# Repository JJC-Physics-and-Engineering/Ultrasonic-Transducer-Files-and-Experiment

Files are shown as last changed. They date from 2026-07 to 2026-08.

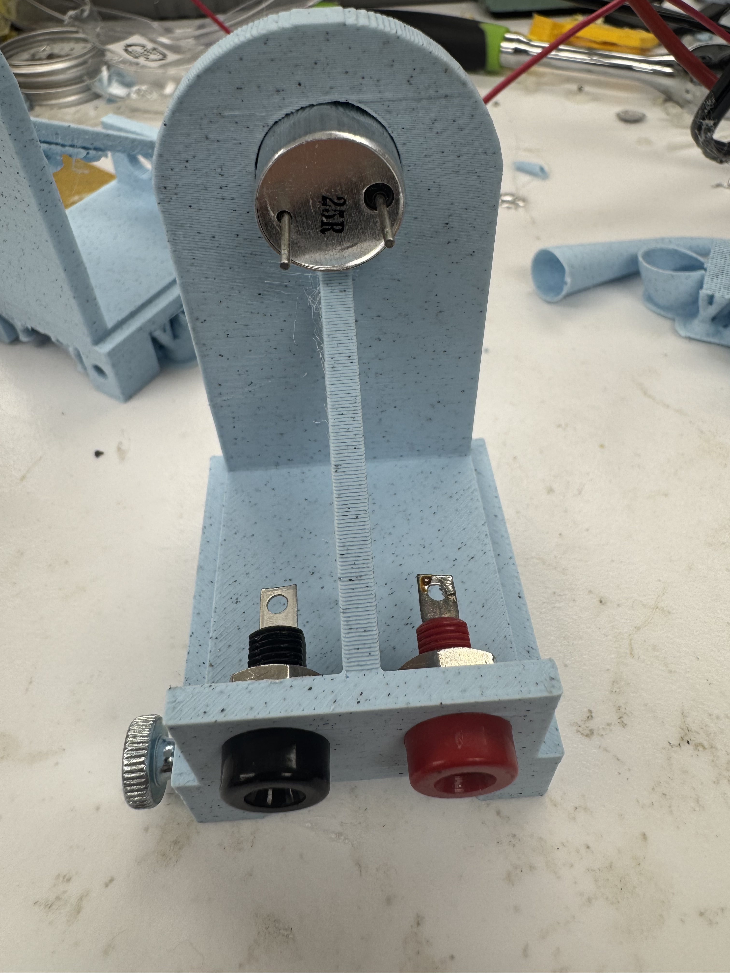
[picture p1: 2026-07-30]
Assembly Instructions/INSTRUCTIONS/Step 5 (Soldering)/1.jpeg

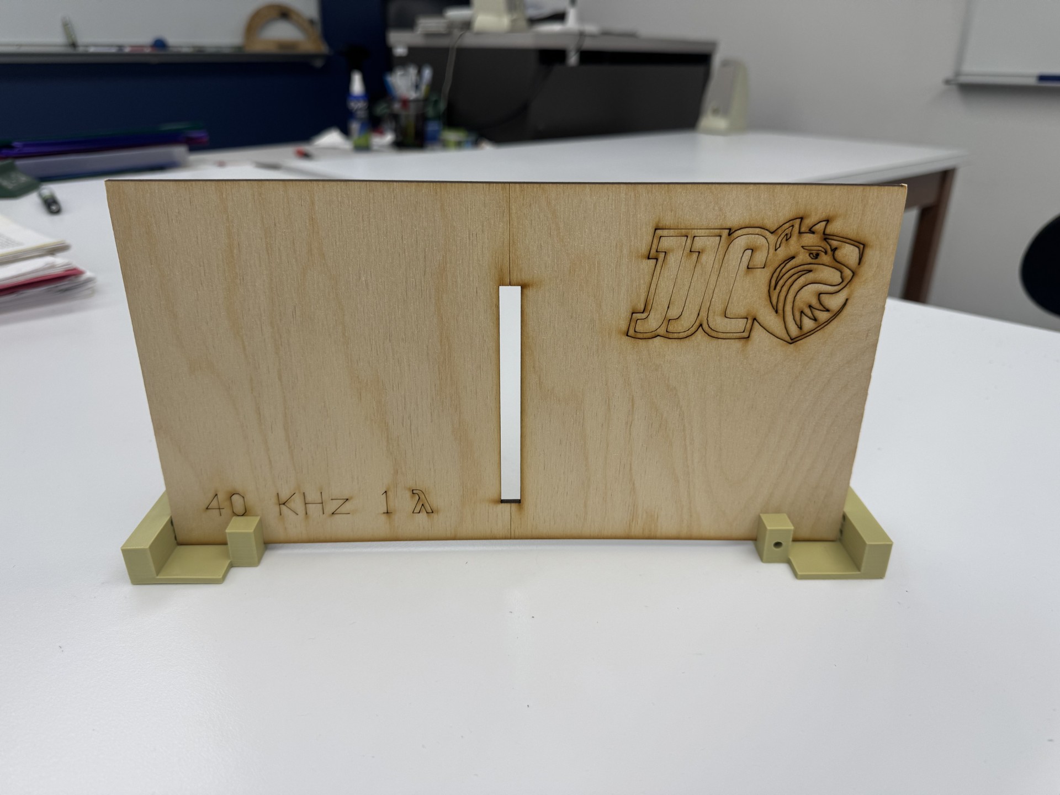
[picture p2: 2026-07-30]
Part Files And Blueprints/Slit experiments/Slit experiment example.jpg

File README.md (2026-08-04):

# Ultrasonic Transducers for the Introductory Physics Laboratory

Open design files, build instructions, and lab activities for a set of low-cost
ultrasonic transmitter/receiver probes used to teach acoustics in introductory
physics laboratory courses.

Each probe is a piezoelectric ultrasonic transducer mounted in a 3D-printed
stand with banana-jack terminals, so it can be driven from an ordinary function
generator and read on an ordinary oscilloscope. The stands clamp to a rail or
meter stick, which makes it straightforward to run quantitative experiments on
the speed of sound, diffraction, and interference with equipment already
present in most teaching labs.

Two frequencies are supported: **25 kHz** and **40 kHz**. Transmitters and
receivers are matched sets — a 25 kHz transmitter must be paired with a 25 kHz
receiver, and likewise for 40 kHz. Color- or shape-coded shrouds make the pairs
easy to tell apart at a glance.

---

## What's in this repository

| Folder | Contents |
| --- | --- |
| [`Part Files And Blueprints/`](Part%20Files%20And%20Blueprints) | CAD source and exports for every printed and cut part: Autodesk Inventor (`.ipt`), STEP (`.stp`), STL, 3MF, and dimensioned PDF blueprints. Also contains the laser-cut slit plates (`.dwg`/`.dxf`). |
| [`3D Print Settings/`](3D%20Print%20Settings) | Recommended slicer settings and plate-orientation screenshots for each printed part. |
| [`Assembly Instructions/`](Assembly%20Instructions) | Parts list with supplier links, required tools and skills, and a photo-illustrated step-by-step build guide. |
| [`Lab activities/`](Lab%20activities) | Student-facing lab handouts — the original experiments plus revised versions written for these transducers, and equipment instructions for the function generator and oscilloscopes. |

---

## Parts to print, cut, and buy

### 3D-printed parts

| Part | Purpose |
| --- | --- |
| Transmitter + Receiver Stand | Holds the transducer and the banana jacks; mounts to a rail or ruler |
| Shrouds (25 kHz T/R, 40 kHz T/R) | Cover the wiring and identify the frequency and role of each probe |
| Ruler square | Reference square for positioning probes along a ruler/rail |
| Slit holder | Holds the laser-cut slit plates upright for diffraction experiments |

All prints were developed on a **Bambu Lab A1** using otherwise standard
profiles. Per-part settings live in `3D Print Settings/<part>/`. In brief:

- Stands, ruler square, and slit holder: 4 wall loops, 30 % cubic infill.
- Shrouds: 2 wall loops, 15 % cubic infill.
- Supports are **on** only for the transmitter/receiver stand; orientation for
  that print matters — see the included example-plate screenshot.
- Several of these prints lift off the plate. A glue stick on the build plate
  is strongly recommended.

Anywhere a part has a **4 mm hole**, it is sized for an M3 heat insert and
thumb screw so the part can be clamped to a rail or ruler.

### Laser-cut parts

Single-slit (λ/4, λ/2, 1λ, 2λ) and double-slit plates are provided for both
25 kHz and 40 kHz, as `.dwg` and `.dxf`. Cut from **20″ × 12″ × 1/8″ plywood**;
choose a plywood with as little resin as possible, since resin-heavy stock cuts
poorly and smokes badly. Laser cutters use proprietary software, so no machine
settings are included — import the DXF into whatever your cutter uses. See
[`Part Files And Blueprints/Slit experiments/READ ME.txt`](Part%20Files%20And%20Blueprints/Slit%20experiments/READ%20ME.txt).

### Purchased parts

Full parts list with supplier links: [`Assembly Instructions/Part List.docx`](Assembly%20Instructions/Part%20List.docx).

**Essential:** ultrasonic transducers (25 kHz and/or 40 kHz transmitter and
receiver pairs), banana jacks with nuts, 18 AWG wire, PLA or PETG filament.
**Optional:** M3 heat inserts, a heat-insert soldering tip, and M3 × 18 mm
thumb screws for rail mounting.

---

## Building a probe

You will need basic soldering skill, basic familiarity with heat inserts, and
patience. Tools: soldering iron and solder, heat-insert tip, wire strippers,
adhesive (super glue, hot glue, or PLA glue), and — highly recommended —
curved needle-nose pliers.

The build is six steps, each with photos in
[`Assembly Instructions/INSTRUCTIONS/`](Assembly%20Instructions/INSTRUCTIONS):

1. **Remove supports** from the printed stand.
2. **Insert heat inserts** into the 4 mm holes.
3. **Insert the transducer.** These are polarized — the positive (black-based)
   prong goes on the right. Press fit or glue.
4. **Insert the banana jacks.** Getting the nuts on without bent needle-nose
   pliers is genuinely painful.
5. **Solder.** Work close to the transducer body and keep the iron moving —
   it is easy to melt the plastic around the jacks or the transducer. Trim the
   transducer prongs short enough that the shroud will seat.
6. **Fit the shroud**, matching it to the transducer's frequency and role.
   Hot glue keeps the probe serviceable; super glue or PLA glue is permanent.

`Assembly Instructions/INSTRUCTIONS/Additional Ideas/` shows how a school logo
can be embedded in the stand (much longer print) or printed separately and
glued on (faster, slightly less clean).

---

## Lab activities

The handouts in [`Lab activities/`](Lab%20activities) are Word documents intended
to be edited for your own course.

**`Original versions from NIU/`** — the source experiments these activities were
built from, along with rewrites tracking the changes made:

- *Experiment 3 — Sinusoidal Motion: The Oscilloscope*
- *Experiment 10 — Speed of Sound* (wavelength via Lissajous figures)
- *Experiment 47 — Acoustic Diffraction and Interference* (single-slit
  diffraction, two-slit interference, Lloyd's mirror, transducer radiation
  pattern)

**`Updated lab activities/`** — revised for these transducers and for modern
benchtop equipment:

- *New speed of sound* — pulse–echo timing. The transmitter is driven in burst
  mode, the reflection off a movable flat surface is timed on the scope, and a
  linear fit of position vs. Δt/2 recovers *c* ≈ 343 m/s.
- *OG Speed of Sound* — the classic wavelength-based version, for comparison.
- *Equipment Instructions* — step-by-step operation of the function generator
  and of both oscilloscope models used in the lab.

Additional activities are planned, including Lloyd's mirror, two-slit
interference, single-slit diffraction, shape detection, airflow between
transducers, and the Doppler effect.

---

## Getting started

1. Print one stand and one shroud per probe, using the settings in
   `3D Print Settings/`. Remember that probes are used in matched pairs.
2. Order the transducers, banana jacks, wire, and (optionally) heat inserts and
   thumb screws from the parts list.
3. Build each probe following `Assembly Instructions/`.
4. Laser-cut the slit plates and print the slit holder and ruler square if you
   plan to run the diffraction and interference activities.
5. Adapt the handouts in `Lab activities/` to your course, checking the
   resonant frequency of the transducers you actually bought.

---

## Repository notes

- CAD is provided as native Inventor `.ipt` alongside neutral STEP and STL, so
  parts can be modified in most CAD packages.
- `.bak`, `.dwl`, and `.dwl2` files in the slit folders are AutoCAD backup and
  lock artifacts; the `.dwg` and `.dxf` files are the ones you want.
- Some folder and file names use the spelling "Reciever". These are preserved
  as-is so paths continue to match the CAD assemblies and instructions.

## Authors and acknowledgments

<!-- TODO: add student and faculty contributors, institution, and any grant or
     program support. -->

The original lab experiments derive from the physics laboratory manual used at
Northern Illinois University and reference T. D. Rossing, *The Science of Sound*.

## License

<!-- TODO: choose a license. For a project like this, a split license is common:
     e.g. CERN-OHL-S or CC BY-SA 4.0 for the hardware and design files, and
     CC BY-NC-SA 4.0 or CC BY 4.0 for the lab handouts. -->

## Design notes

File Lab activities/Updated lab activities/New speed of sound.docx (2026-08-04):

Experiment 10

SPEED OF SOUND

APPARATUS: Ultrasonic crystals, audio generator, oscilloscope

DISCUSSION: The speed of sound in an ideal gas is given by:

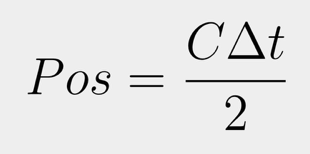
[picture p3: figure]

Pos is position C is speed of sound t is time

Your ultrasonic transducers may have a different resonant frequency. You may need to check with your instructor.

The sound waves are reflecting off the surface and back causing the change in time to be double, in order to account for this delta t is divided by 2.

PROCEDURE:

1. Drive the transmitting crystal with an audio generator and connect the receiving crystal to the vertical input of an oscilloscope. With the receiver and transmitter next to each other and a solid flat surface 5 cm in front of them, tune the generator to the resonant frequency of the crystals.

2. Set the function generator to resonant frequency with 5V peak to peak (Vpp) and use burst at 6 cycles with one second burst period. Set the oscilloscope by using both cursors (one for beginning of the transmitter wave and one for the beginning of the receiver wave) and use time scale 1 millisecond division.

3. Take many recordings of the position of the solid flat surface vs the time delay (the delta t). Record in the table attached.

4. In Logger Pro, input time delay in the x column. Then input the position in the y column. The final product will have (delta t/2) in seconds (if your time is in milliseconds, divide by 1000) on the x-axis and position in meters (if your position is in cm, divide by 100 to get to meters) on the y-axis. When this is achieved, click analyze > linear fit. The slope should be around 343 m/s.

DATA SHEET AND MINI-REPORT: Experiment 10

Position (cm) | Delta t (ms)
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
C = ___________ m/s

*The specific numbers chosen for the position do not matter. The above numbers are suggestions not recommendations.

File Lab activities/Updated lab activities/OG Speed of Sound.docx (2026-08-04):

Experiment 10

SPEED OF SOUND

APPARATUS: Ultrasonic crystals, audio generator, oscilloscope

REFERENCE: Rossing, The Science of Sound, Section 3.5

DISCUSSION: The speed of sound in an ideal gas is given by:

T is absolute temperature M is molecular weight R is the gas constant.

Note that the speed varies directly with temperature but is independent of pressure. (In a real gas, there is a slight dependence on pressure, but it is quite small).

In this experiment, the speed of sound is determined by measuring frequency and wavelength and using the relationship: v = fγ. The sound source and receiver are both ceramic crystals of the type formerly used in television remote control units. (Remote controls of this type used to make an audible “click”. For this reason, they were referred to as “clickers”.) They resonate at about 40 kHz, well above the limit of hearing (dogs or bats might not enjoy this experiment!). Your ultrasonic transducers may have a different resonant frequency. You may need to check with your instructor.

PROCEDURE:

1. Drive the transmitting crystal with an audio generator, and connect the receiving crystal to the vertical input of an oscilloscope. With receiver and transmitter 5 – 10 cm apart, tune the generator to the resonant frequency of the crystals.

2. To measure the wavelength, vary the distance between the crystals, and locate positions that are some integral number of wavelengths apart. This can be done by connecting the receiving crystal to the vertical input of the oscilloscope, and the generator output to the horizontal input, to display a fy vs fx Lissajous pattern whose shape varies with the phase of the signal from the receiver.

Since the precision of the result depends strongly on the measurement of the wavelength, it is wise to average several measurements to determine the best value of λ. One way to do this would be to make 6 or more determinations of 10λ using different initial spacings of receiver and transmitter (why measure 10λ rather than λ?)

3. Measure the frequency of the audio generator with a frequency counter. Calculate the speed of sound from the formula: v = fγ. Compare it to the value given in Table 3.1 of Rossing (corrected to the temperature in your room.)

If time permits:

4. Measure the attenuation of 40 kHz ultrasound by various materials (paper, Styrofoam, etc.) by noting the difference in amplitude of the signal with and without the absorber in its path.

DATA SHEET AND MINI-REPORT: Experiment 10

10λ (cm) | Frequency (Hz)

To find the wavelength: Take all the lengths found for 10λ, add them together, and divide them by 6 (or however many determinations found). This number is your average for 10λ. Take the average for 10λ and divide it by 10 to find λ.

λ = _______m

t = ______ °C

V(t) = ______

v = fγ

T = ________K

Discussion: Estimate the uncertainty in λ and f. Call these Δλ and Δf.

Calculate the uncertainty in speed Δv from the formula:

Does v Δv span the calculated value v(T)?

27 SPEED OF SOUND

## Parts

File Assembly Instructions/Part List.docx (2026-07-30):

Parts List

ESSENTIAL

- Banana Jacks: https://www.mouser.com/en/ProductDetail/530-108-0903-1  https://www.mouser.com/en/ProductDetail/Johnson-Cinch-Connectivity-Solutions/108-0902-001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
- Transducers: https://a.co/d/07uBKIS6  https://a.co/d/09vyZoEI  https://a.co/d/0f3AuWEN
- 18 Gauge Wire
- PETG/PLA Filament

Optional

- M3 Heat Inserts: https://a.co/d/02u2SNHs
- Heat Insert Tips: https://a.co/d/04KGmkFV
- M3 X 18mm Thumb Screws: https://a.co/d/0bNqlTka

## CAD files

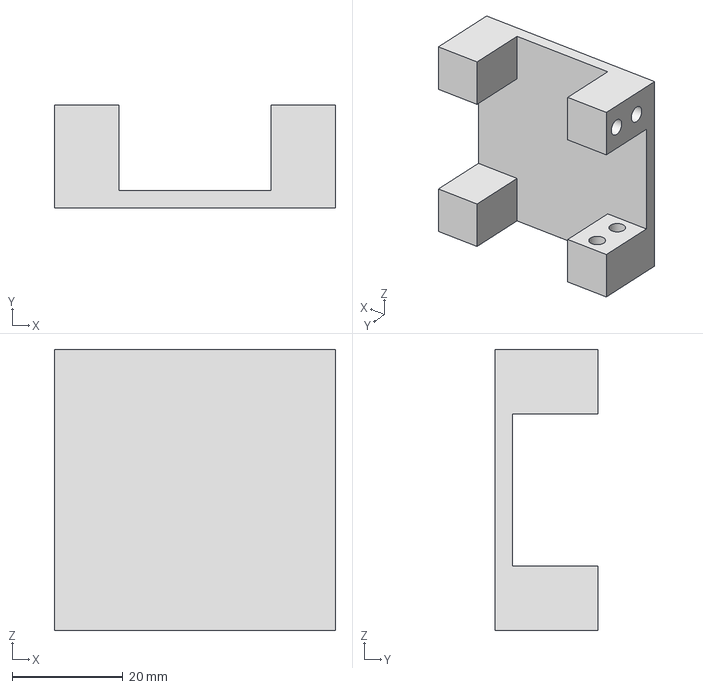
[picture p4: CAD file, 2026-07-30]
Part Files And Blueprints/Ruler square/Ruler square.stp
50.8 x 18.7 x 50.8 mm

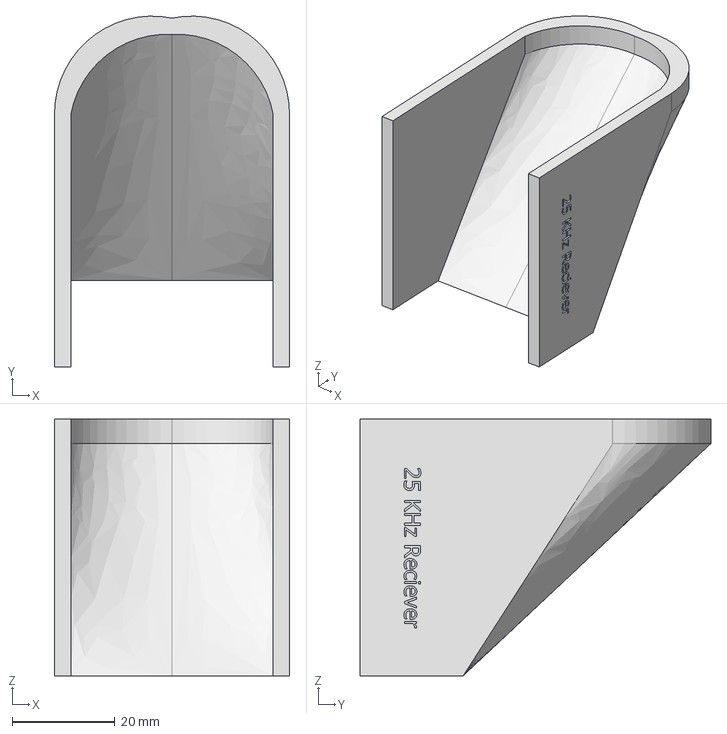
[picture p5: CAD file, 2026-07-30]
Part Files And Blueprints/Shrouds/25Khz Reciever/Shroud 25 R.stp
45.7 x 68.2 x 50.0 mm

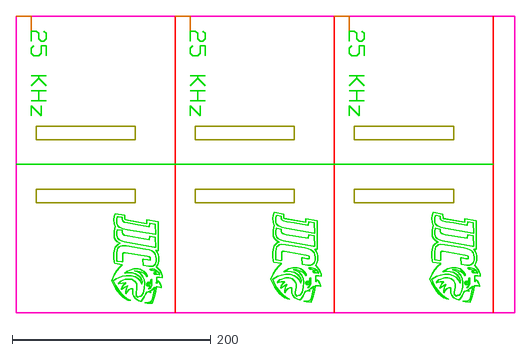
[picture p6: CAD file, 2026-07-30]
Part Files And Blueprints/Slit experiments/Double Slit 25Khz/25 Khz double slit.dxf
501.6 x 298.5

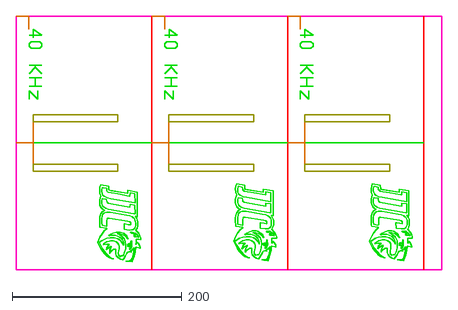
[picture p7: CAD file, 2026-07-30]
Part Files And Blueprints/Slit experiments/Double Slit 40Khz/40 Khz double slit.dxf
501.7 x 298.5

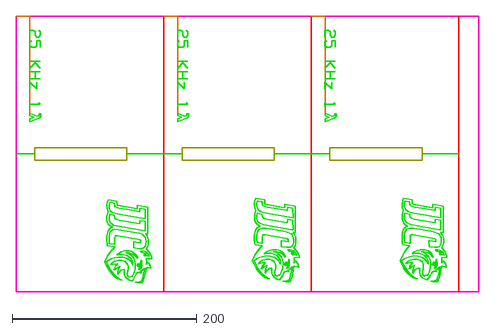
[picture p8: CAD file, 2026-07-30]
Part Files And Blueprints/Slit experiments/Single Slit 25Khz/1/25 Khz single 1.dxf
501.6 x 298.5

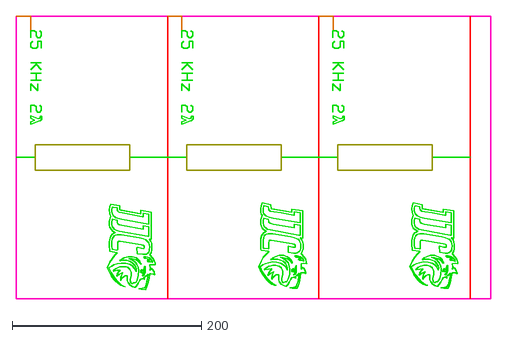
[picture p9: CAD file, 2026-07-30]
Part Files And Blueprints/Slit experiments/Single Slit 25Khz/2/25 Khz single 2.dxf
501.6 x 298.5

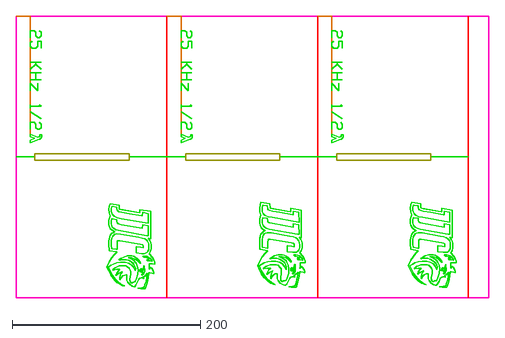
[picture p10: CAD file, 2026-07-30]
Part Files And Blueprints/Slit experiments/Single Slit 25Khz/half/25 Khz single half.dxf
501.6 x 298.5

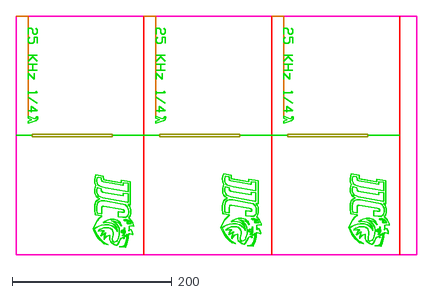
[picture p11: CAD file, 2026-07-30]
Part Files And Blueprints/Slit experiments/Single Slit 25Khz/quarter/25 Khz single quarter.dxf
501.6 x 298.5

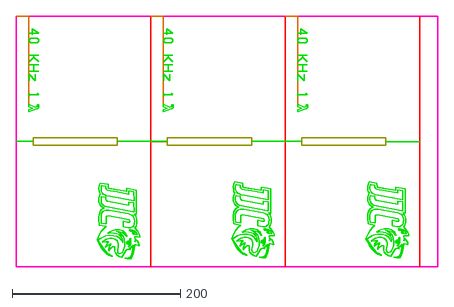
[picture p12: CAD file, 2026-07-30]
Part Files And Blueprints/Slit experiments/Single Slit 40Khz/1/40 Khz single 1.dxf
501.6 x 298.4

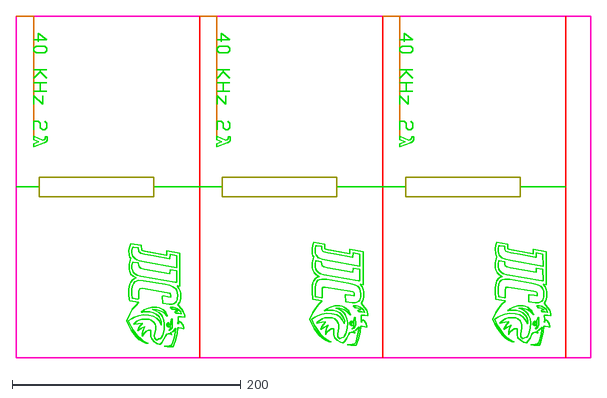
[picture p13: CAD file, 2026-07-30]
Part Files And Blueprints/Slit experiments/Single Slit 40Khz/2/40 Khz single 2.dxf
501.6 x 298.5

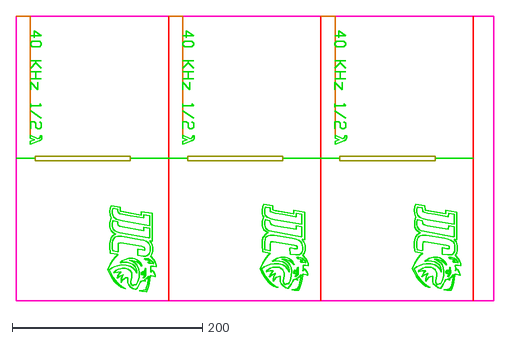
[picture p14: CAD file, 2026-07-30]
Part Files And Blueprints/Slit experiments/Single Slit 40Khz/half/40 Khz single half.dxf
501.6 x 298.5

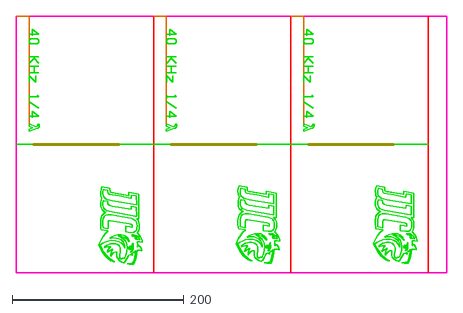
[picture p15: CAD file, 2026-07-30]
Part Files And Blueprints/Slit experiments/Single Slit 40Khz/quarter/40 Khz single quarter.dxf
501.6 x 298.5

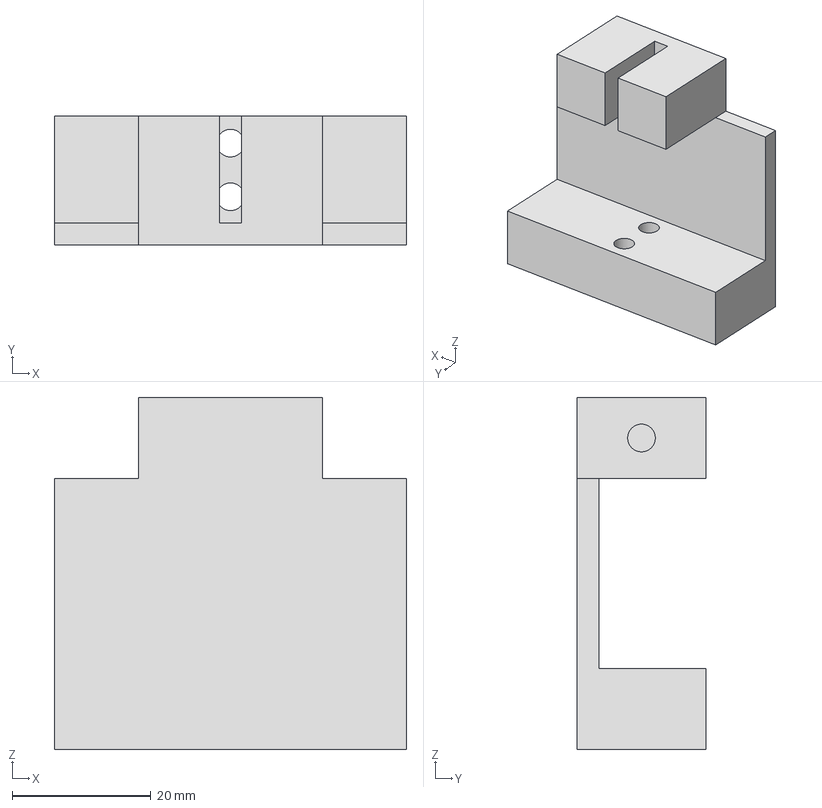
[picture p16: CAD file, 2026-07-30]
Part Files And Blueprints/Slit experiments/Slit experiment holder/Slit holder.stp
50.8 x 18.7 x 50.8 mm

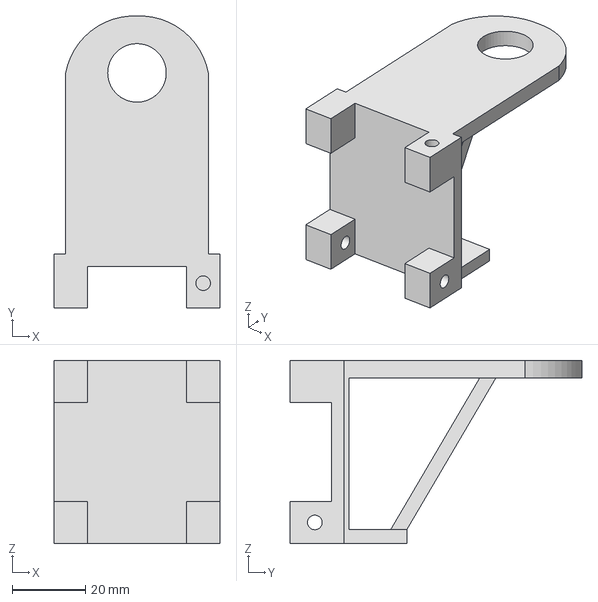
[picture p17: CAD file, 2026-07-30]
Part Files And Blueprints/Transmitter + Reciever Stand/Transmitter + Reciever.stp
45.3 x 79.8 x 50.0 mm

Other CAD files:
Part Files And Blueprints/Shrouds/25Khz Transmitter/Shroud 25 T.stp
Part Files And Blueprints/Shrouds/40Khz Reciever/Shroud 40 R.stp
Part Files And Blueprints/Shrouds/40Khz Transmitter/Shroud 40 T.stp
Part Files And Blueprints/Ruler square/Ruler square.ipt
Part Files And Blueprints/Ruler square/Ruler square.stl
Part Files And Blueprints/Shrouds/25Khz Reciever/Shroud 25 R.3mf
Part Files And Blueprints/Shrouds/25Khz Reciever/Shroud 25 R.ipt
Part Files And Blueprints/Shrouds/25Khz Reciever/Shroud 25 R.stl
Part Files And Blueprints/Shrouds/25Khz Transmitter/Shroud 25 T.ipt
Part Files And Blueprints/Shrouds/25Khz Transmitter/Shroud 25 T.stl
Part Files And Blueprints/Shrouds/40Khz Reciever/Shroud 40 R.ipt
Part Files And Blueprints/Shrouds/40Khz Reciever/Shroud 40 R.stl
Part Files And Blueprints/Shrouds/40Khz Transmitter/Shroud 40 T.ipt
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

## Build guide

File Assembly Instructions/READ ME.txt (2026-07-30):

In Order to Assemble a Transmitter or Receiver You Need to Have the Following Tools, Parts, and Skills

--------------------------------------------------

SKILLS

--------------------------------------------------

Basic proficiency with a soldering iron

Basic use of heat inserts

Patience

--------------------------------------------------

TOOLS

--------------------------------------------------

Soldering Iron

Solder

Heat insert insertion tip

Curved needle nose pliers (Optional)

Some type of adhesive (either Super glue, Hot glue, or PLA glue)

Wire stripers

--------------------------------------------------

Parts

--------------------------------------------------

Transmitter or Receiver Stand

Transmitter or Receiver

Banana Jacks with nuts

18 gauge wire

Shroud

Heat Inserts

--------------------------------------------------

Notes

--------------------------------------------------

I will include a visual step by step guide in the form of txt and png files labeled in numerical order

Just a reminder that these probes are a set so you MUST have a 25Khz receiver paired with a 25Khz transmitter and the same applies to the 40Khz receivers and transmitters.

--------------------------------------------------

IMPORTANT

--------------------------------------------------

WHEREVER YOU SEE A 4mm HOLE ON ANY PART, IT IS DESIGNED FOR A HEAT INSERT AND THUMB SCREW TO ALLOW YOU TO SECURE THE PART TO A RAIL/RULER.

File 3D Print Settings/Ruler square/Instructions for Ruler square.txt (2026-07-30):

3D Print Settings

All prints use standard print settings for Bambu A1 unless stated

----------

Wall Loops: 4

Sparse Density Infill: 30%

Sparse Infill Pattern: Cubic

Enable Support: OFF
----------

Notes

This Print Likes to lift off of the plate. Use a glue stick on the plate to avoid this.

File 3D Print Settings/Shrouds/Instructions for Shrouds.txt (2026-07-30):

3D Print Settings

All prints use standard print settings for Bambu A1 unless stated

----------

Wall Loops: 2

Sparse Density Infill: 15%

Sparse Infill Pattern: Cubic

Enable Support: OFF

----------

Notes

Print is prone to fail early on. watch the 3D printer closely until the first few layers are complete. Glue Stick on the plate helps tons.

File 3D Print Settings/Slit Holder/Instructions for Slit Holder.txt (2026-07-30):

3D Print Settings

All prints use standard print settings for Bambu A1 unless stated

----------

Wall Loops: 4

Sparse Density Infill: 30%

Sparse Infill Pattern: Cubic

Enable Support: OFF

----------

Notes

Once again this print likes to lift off of the plate so using a glue stick on the plate helps a lot.

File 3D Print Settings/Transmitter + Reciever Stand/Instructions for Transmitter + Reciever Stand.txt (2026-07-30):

3D Print Settings

All prints use standard print settings for Bambu A1 unless stated

----------

Wall Loops: 4

Sparse Density Infill: 30%

Sparse Infill Pattern: Cubic

Enable Support: ON

----------

Notes

Orientation is very important for this print. Please see included screenshot for proper orientation.

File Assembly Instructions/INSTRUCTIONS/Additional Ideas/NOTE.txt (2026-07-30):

It is possible to embed your schools logo into the stand which makes them much more visually appealing however this effects the length of the print GREATLY.

I choose to print my schools logo separately and glue them on which is not as clean looking but is much faster and less complex.

I will provide examples of both so you can decide if it is worth the effort.

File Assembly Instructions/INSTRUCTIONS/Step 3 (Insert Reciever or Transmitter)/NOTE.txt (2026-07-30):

I usually press fit these in but feel free to glue them in if you wish.

Also these are polarized so mate sure you have the positive (black based prong) on the right side.

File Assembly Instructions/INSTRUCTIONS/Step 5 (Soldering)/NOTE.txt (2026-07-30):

Take your time here, since it is very easy to overheat the banana jacks or transmitter/receiver while soldering which can melt the plastic around both of them.

Also you will need to trim the prongs of the receiver/transmitter down so the shroud can fit on the stand so try to solder close to the body of the receiver/transmitter.

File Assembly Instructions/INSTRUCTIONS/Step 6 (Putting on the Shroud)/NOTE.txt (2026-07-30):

Make sure that your specific transmitter/receiver has its corresponding shroud so it is easy to tell which probes are which at a glance.

I used hot glue to secure the shroud to the stand so It could be serviced in the future. If serviceability isn't a concern to you feel free to superglue or PLA glue the two parts together

If using hot glue I HIGHLY recommend the Stanley hot glue sticks since they seem to work the best in my opinion

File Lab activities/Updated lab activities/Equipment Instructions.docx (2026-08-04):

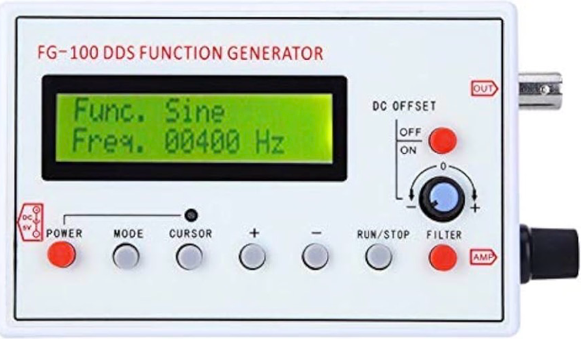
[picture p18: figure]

How to use the function generator and oscilloscopes:

Function generator:

- To allow it to power on, use a DC plug on the left side and have it connected to a power outlet. Click the power button.
- On the right side, using the top silver output insert a splitter with banana jacks.
- One set of the red and black cords will connect to the oscilloscope, and the other set will connect to the transmitter.
- The mode button will change how the waves appear on the screen of the oscilloscope. The main mode used is sine.
- The cursor button allows you to move digits to the right and the plus or minus will change the number where the cursor is over.
  - If using a 40KHz receiver and transmitter, the number should read 40000 Hz.
- The DC offset button will move the yellow line on the oscilloscope up or down.
- The AMP dial will make the sound waves on your screen appear bigger or smaller.
- When all the settings are correct, click the run/stop button. If any setting ever needs to be changed, click the run/stop button to edit the settings.

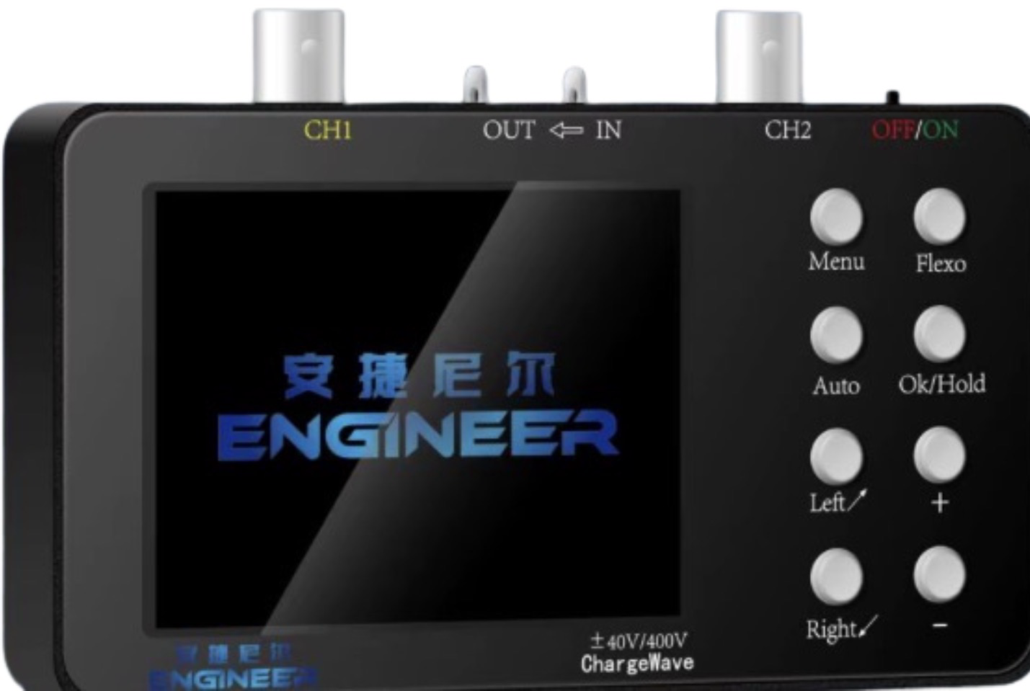
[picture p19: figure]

Oscilloscope 1:

- To power on, plug in USB-C cord into the right side of the oscilloscope and flip it to on with the switch on the top right. If fully charged, it will not need to be plugged in.
- Put splitters on each of the silver channels on the top. Insert the second set of black and red cords from the function generator into the splitter of CH1.
- In the splitter of CH2, insert the black and red cords from the receiver.
- The left and right buttons are used to move the cursor to allow for things on the screen to be selected and changed. Things can be changed by using the + and – buttons.
- The Ok/Hold button pauses the screen.
- In the top right corner of the screen there is a box that can say auto, single, or normal. Single freezes the screen and auto is the most used.
- The top and bottom left boxes are not needed to be changed. Auto can be used instead.
- The bottom middle box when increased, zooms out and vice versa.

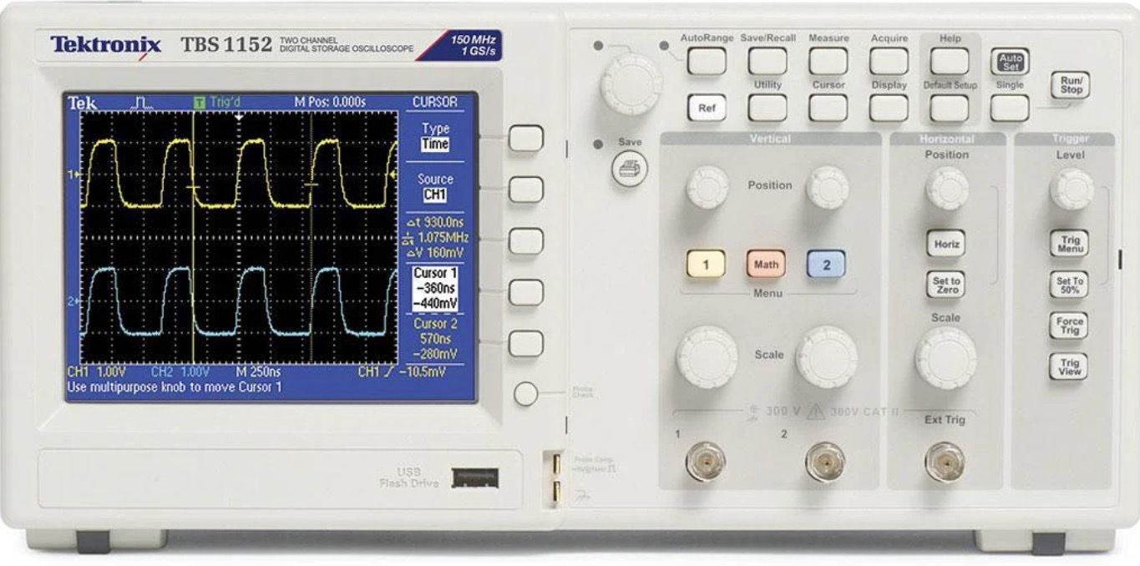
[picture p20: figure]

Oscilloscope 2

- Plug power cord in back and connect to power source.
- Put splitters on each of the silver channels on the bottom of the front. Insert the second set of black and red cords from the function generator into the splitter of 1.
- In the splitter of 2, insert the black and red cords from the receiver.
- Power button is top left of machine, press it down to turn it on.
- In the vertical dark grey rectangle, there are four dials.
  - The top left dial moves the yellow wave from the transmitter up or down.
  - The top right dial moves the blue wave from the receiver up or down.
  - The bottom left dial makes the yellow wave bigger or smaller.
  - The bottom right dial makes the blue wave bigger or smaller.
- The Horizontal box only has two dials.
  - The top one moves both waves to the left and right.
  - The bottom one makes it take longer or shorter to move across the screen.
- The trigger box only has one dial.
  - It freezes the trace.
- The top dial, not in any box, changes the setting from auto to triggered.

SET UP PICTURED:

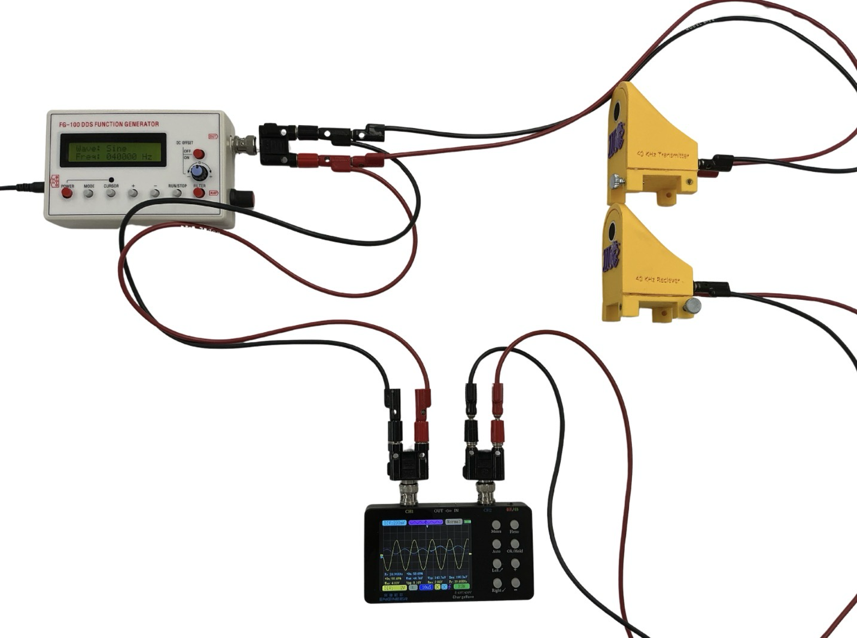
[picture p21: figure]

Instruction manual for how to use the equipment needed for the experiments

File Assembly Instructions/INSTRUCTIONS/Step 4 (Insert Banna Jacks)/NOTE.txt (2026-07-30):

If you don't have bent needle nose pliers getting the nuts on the banana jacks is a real pain.

If you don't care about future serviceability gluing in the banana jacks could also work and would save time.

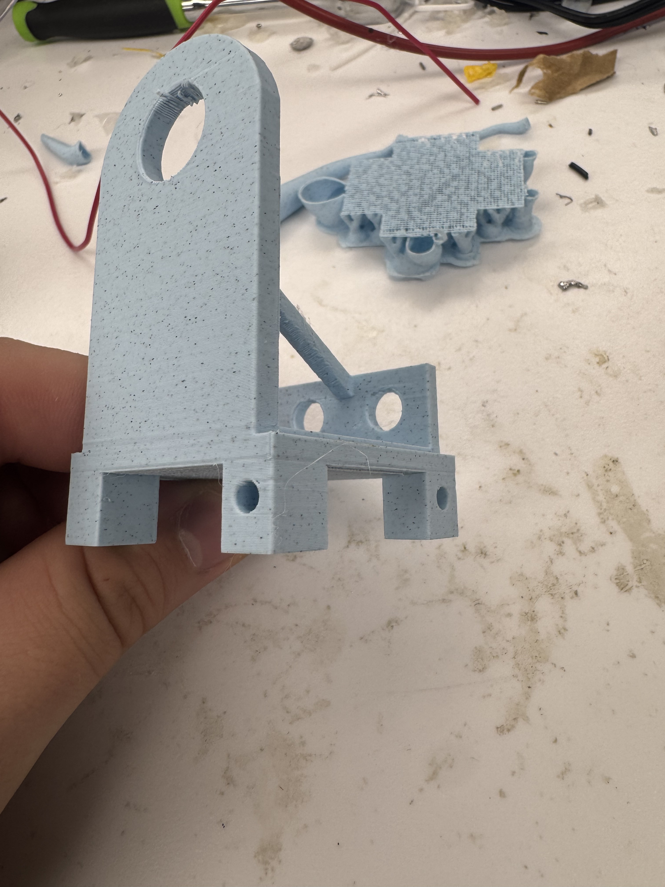
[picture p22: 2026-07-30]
Assembly Instructions/INSTRUCTIONS/Step 2 (Insert Heat Insets)/1.jpeg

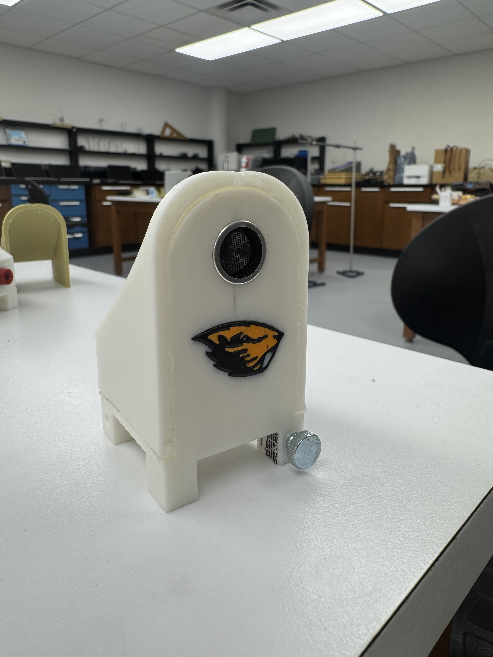
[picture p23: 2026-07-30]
Assembly Instructions/INSTRUCTIONS/Additional Ideas/2.jpeg

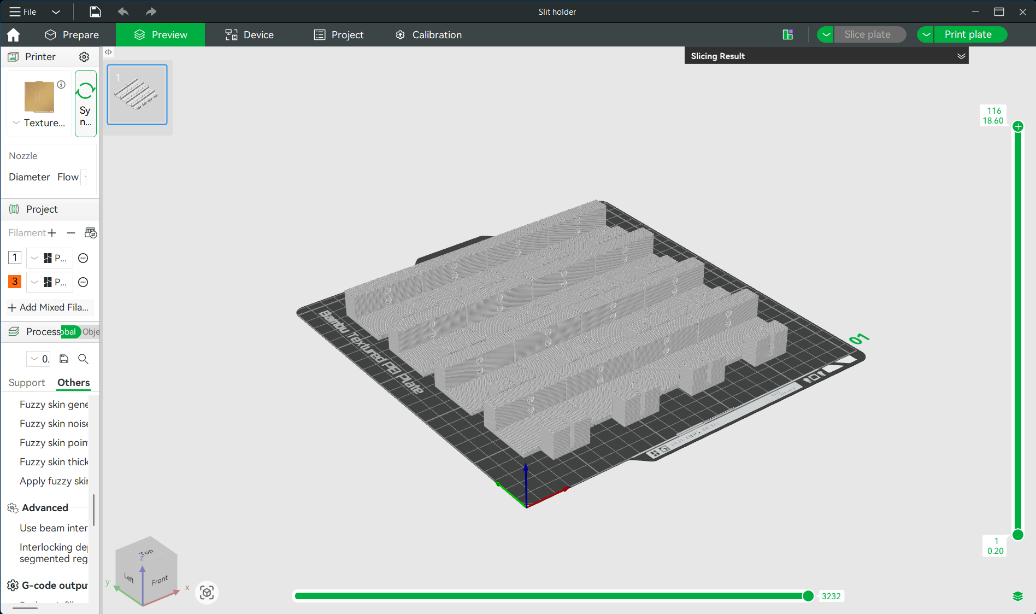
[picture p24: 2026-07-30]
3D Print Settings/Slit Holder/Example plate.png

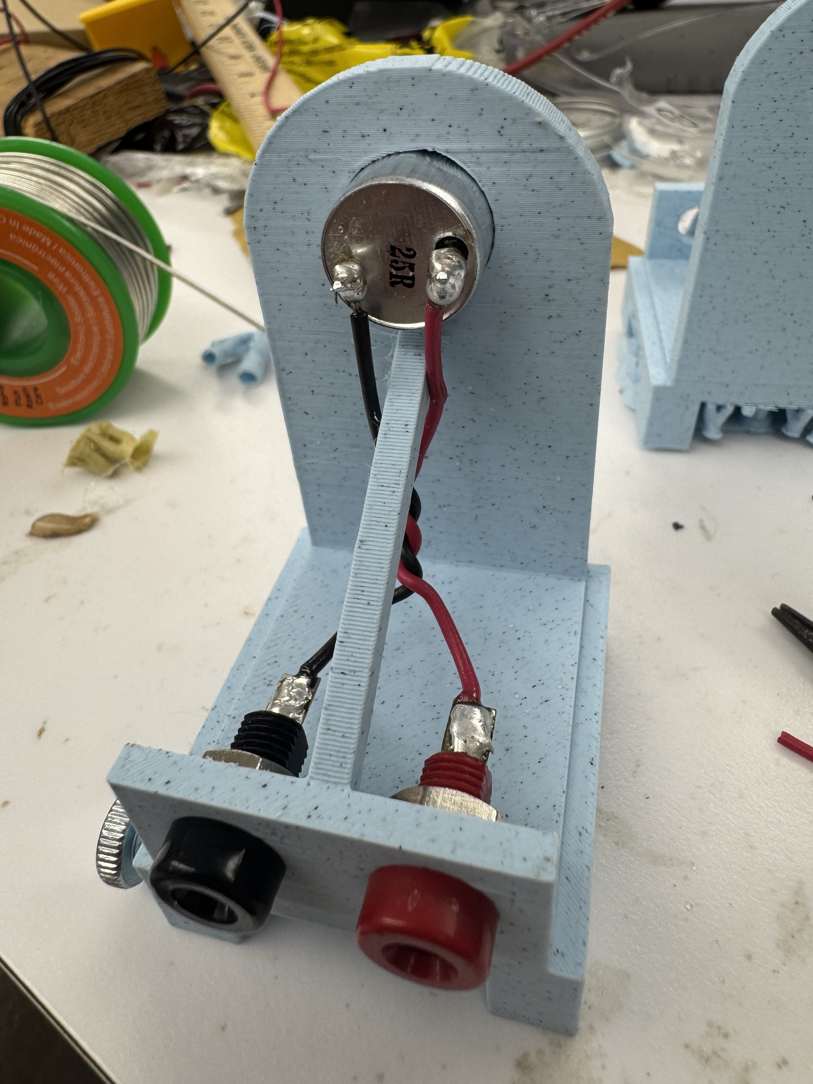
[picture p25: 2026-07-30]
Assembly Instructions/INSTRUCTIONS/Step 5 (Soldering)/3.jpeg

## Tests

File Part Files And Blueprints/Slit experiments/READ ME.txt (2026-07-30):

In Regards to the slit experiments:

I decided to include the files for the slit experiments since I A) already made them, and B) They are a good introduction to how our probes work. However, I am unable to provide clear instructions on the setup and settings of the laser cutter that made them since unlike 3D printers, laser cutters tend to use their own proprietary software that makes any instructions here pointless for most users. So I am unable to provide clear instructions but I am able to provide the files used, what materials we used, and photo of the finished product. The included DXF files should be able to be imported to most laser cutting software pretty easily.

MATERIAL:

20'' X 12'' X 1/8'' Plywood

NOTES:

Try to get a plywood with as little resin as possible since high amounts of resin are harder to cut and produce MUCH more smoke.

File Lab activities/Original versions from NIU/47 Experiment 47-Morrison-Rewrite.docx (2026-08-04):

Experiment 47

ACOUSTIC DIFFRACTION AND INTERFERENCE

APPARATUS: Ultrasonic crystals, audio generator, oscilloscope, and audio voltmeter.

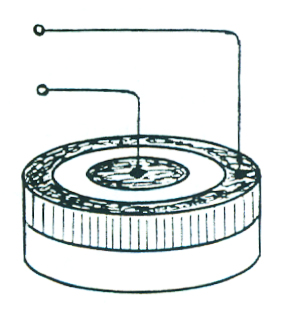
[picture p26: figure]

REFERENCES: T.D. Rossing, The Science of Sound, Sections 3.10, 3.11; A.M. Portis and H.D. Young, Berkeley Physics Laboratory, 2nd ed. (McGraw-Hill, New York, 1971). AF-2; F.W. Sears, M.W. Zemansky, and H.D. Young, College Physics, 5th ed. (Addison-Wesley, Reading, MA, 1980). Chapter 42.

DISCUSSION:

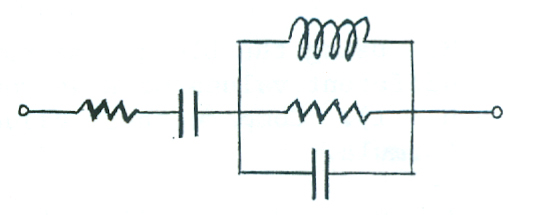
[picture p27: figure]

This experiment makes use of the same ultrasonic transducers used to determine the speed of sound in Experiment 10. These transducers, which were developed for the remote control of television receivers, consist of discs of piezoelelctric barium titanate bonded to aluminum. Two electrodes are attached to each barium titanate disc and applying a voltage to these electrodes causes the BaTiO3 to warp, thus exciting a strong mechanical resonance at 40 kHz in the aluminum disc (other resonances can also be observed at high frequencies.) An equivalent electrical circuit for the transducer is shown.

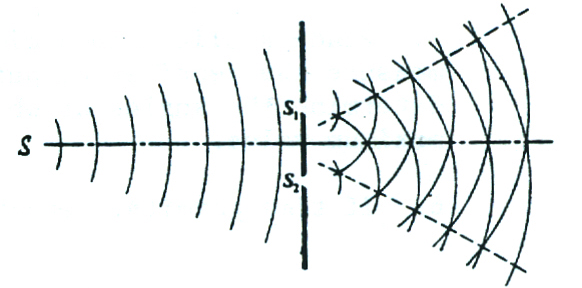
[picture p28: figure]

Many classical optics experiments can be conveniently performed using these transducers to generate and detect ultrasonic single-slit diffraction, two-slit interference, and Lloyd’s mirror. In addition, the radiation pattern of a single transducer will be explored.

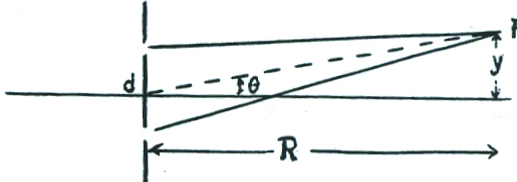
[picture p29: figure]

One of the earliest demonstrations of wave interference was performed by Thomas Young around 1800. Waves from source S pass through slits S1 and S2 and interfere in the region beyond them. Constructive interference will occur at point P located so that y = R nλ/d where d is the distance between the slits, λ is the wavelength, and n is an integer

Lloyd’s mirror may be thought of as a variation of Young’s experiment in which the image S1 of source S acts as the second source. Because there is a reversal of phase upon reflection at the table top, however, S and S1 act as sources with opposite phase (compare Fig. 25.2 in Rossing)

Therefore, constructive interference should occur when ;

but y = d/2, so we can write

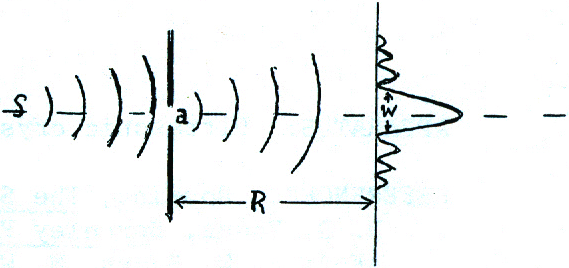
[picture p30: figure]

as the condition for a maximum.

The diffraction pattern of a single slit consists of a central maximum along with secondary maxima on either side. The width w of the central maximum is given approximately by , where a is the width of the slit.

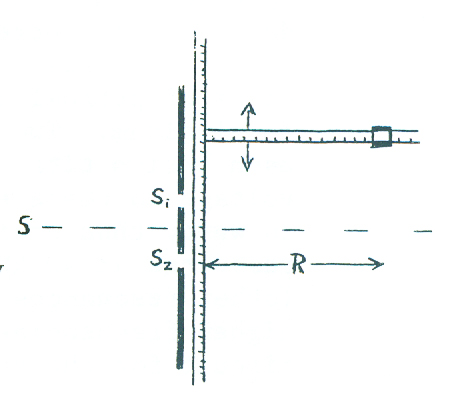
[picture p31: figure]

PROCEDURE:

1. Set up the transmitting and receiving crystals as described in Experiment 10. Either measure the wavelength (as in Step 2) or calculate it from the measured frequency.

2. Place one crystal about 50 cm away from a pair of slits having a spacing of about 5 cm. With R = 50 cm, measure y for 5-7 maxima (2 or 3 on each side of the central one). Compare these values of y to those predicted by the formula again.

3. Using the Lloyd’s mirror arrangement, measure as many different values or R as you can (including the one for n = 1). Compare these values to those predicted by the formula.

4. Connect an audio voltmeter (VTVM) across the receiver crystal in order to more accurately measure small voltages. Carefully measure the output of the receiving transducer placed at intervals of 15° on a semicircle with the transmitter at the center. Determine the average angles at which the signal drops to one half of its value on the axis. At what angle does it drop to one tenth of its maximum value?

5. Place a slit with a width of about 2λ about 20 cm away from the transmitter and measure the receiver output on a semicircle with the slit at the center. Again determine the angles at which the signal drops to one half and one tenth of its maximum value.

6. If time permits, repeat Step 5 with a slit having a width of about ½.

143 ACOUSTIC DIFFRACTION AND INTERFERENCE

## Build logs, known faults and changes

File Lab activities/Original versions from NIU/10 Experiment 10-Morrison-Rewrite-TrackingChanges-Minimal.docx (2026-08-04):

Experiment 10

SPEED OF SOUND

APPARATUS: Ultrasonic crystals, audio generator, oscilloscope

REFFERENCE: Rossing, The Science of Sound, Section 3.5

DISCUSSION:

The goal of this experiment is to experimentally determine the speed of sound in air using ultrasonic transducers. One transducer will function as a sound wave transmitter; the other transducer will function as a sound wave receiver.

PROCEDURE:

1. Drive the transmitting crystal with an audio generator and connect the receiving crystal to the vertical input of an oscilloscope. Spend a few minutes familiarizing yourself with the qualitative behavior of the transducers.

Determine the resonant frequency of the crystals.

2. Devise a method of measuring the wavelength of the sound wave emitted by the transmitting transducer. It may be useful to connect the receiving crystal to the vertical input of the oscilloscope, and the generator output to the horizontal input, to display a fy vs fx Lissajous pattern whose shape varies with the phase of the signal from the receiver.

Be sure to be able to discuss the precision with which you can determine the wavelength.

3. Record the frequency of the signal from the audio generator with a frequency counter. Calculate the speed of sound. Compare it to the value given in Table 3.1 of Rossing (corrected to the temperature in your room.)

If time permits:

4. Measure the attenuation of 40 kHz ultrasound by various materials (paper, Styrofoam, etc.) by noting the difference in amplitude of the signal with and without the absorber in its path.

DATA SHEET AND MINI-REPORT : Experiment 10

(To be used if a laboratory notebook is not kept)

λ = m v = fγ

t = °C T = K

v(T) =

2, 3)

| 10λ | f
| cm | Hz
Average

Discussion: Estimate the uncertainty in λ and f. Call these Δλ and Δf.

Calculate the uncertainty in speed Δv from the formula:

Does v Δv span the calculated value v(T)?

4)

27 SPEED OF SOUND

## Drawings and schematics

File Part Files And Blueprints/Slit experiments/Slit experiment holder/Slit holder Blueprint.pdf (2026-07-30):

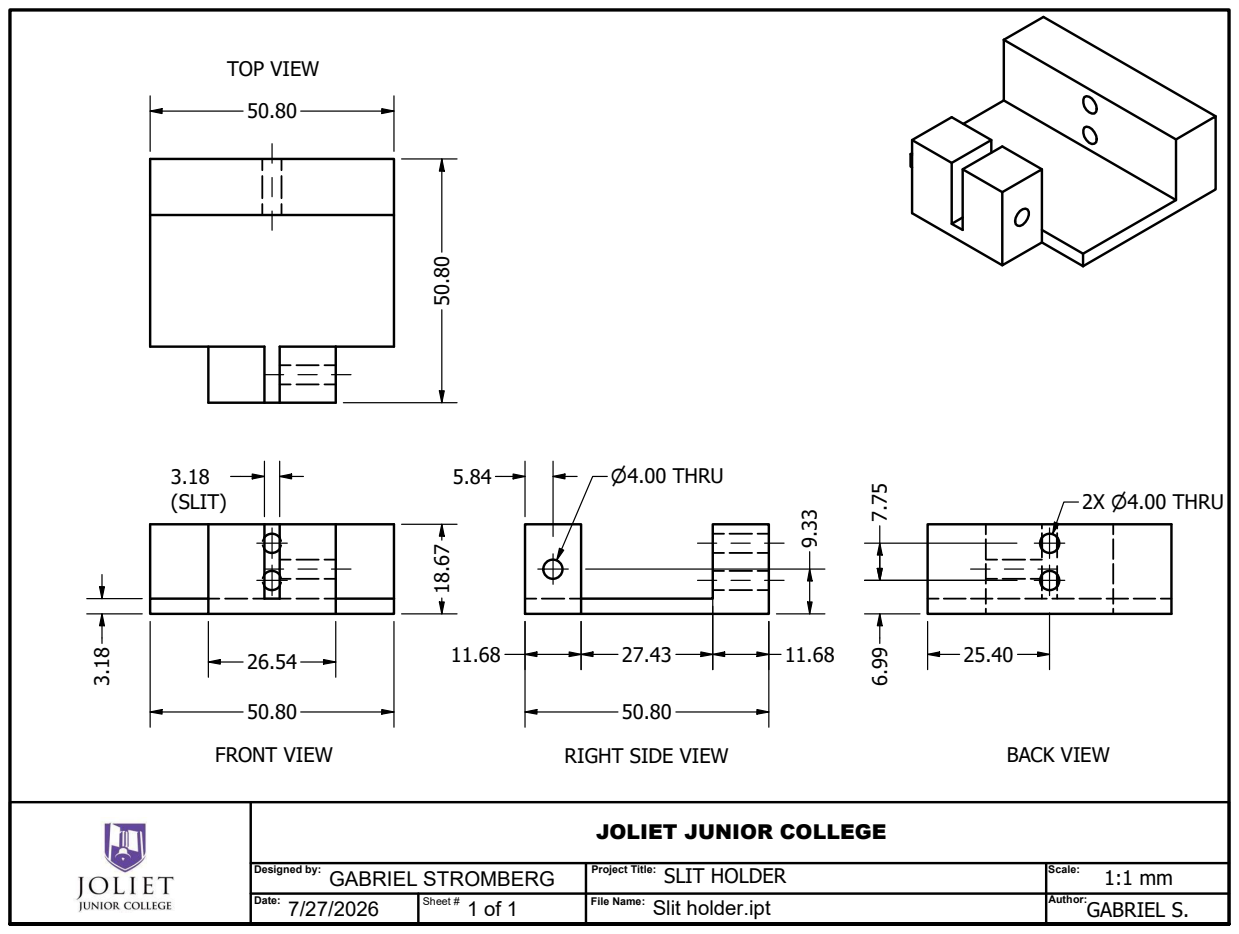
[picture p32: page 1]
⌀4.00 THRU; 2X ⌀4.00 THRU; TOP VIEW; FRONT VIEW; RIGHT SIDE VIEW; BACK VIEW

JOLIET JUNIOR COLLEGE

Designed by: GABRIEL STROMBERG | Project Title: SLIT HOLDER | Scale: 1:1 mm

Date: 7/27/2026 | Sheet # | File Name: Slit holder.ipt | Author: GABRIEL S.

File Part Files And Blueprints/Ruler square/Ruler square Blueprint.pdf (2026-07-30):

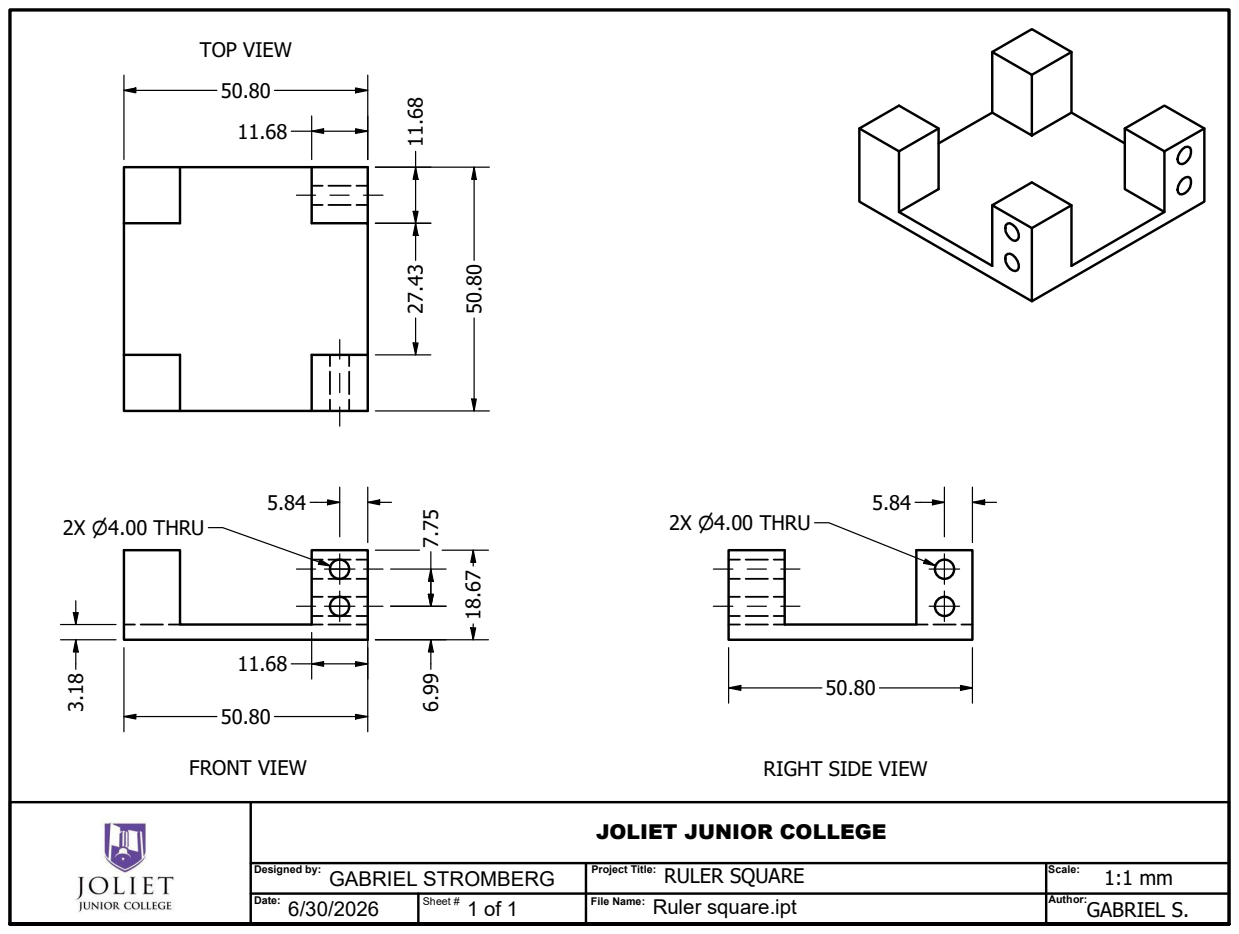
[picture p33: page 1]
2X ⌀4.00 THRU; TOP VIEW; FRONT VIEW; RIGHT SIDE VIEW

JOLIET JUNIOR COLLEGE

Designed by: GABRIEL STROMBERG | Project Title: RULER SQUARE | Scale: 1:1 mm

Date: 6/30/2026 | Sheet # | File Name: Ruler square.ipt | Author: GABRIEL S.

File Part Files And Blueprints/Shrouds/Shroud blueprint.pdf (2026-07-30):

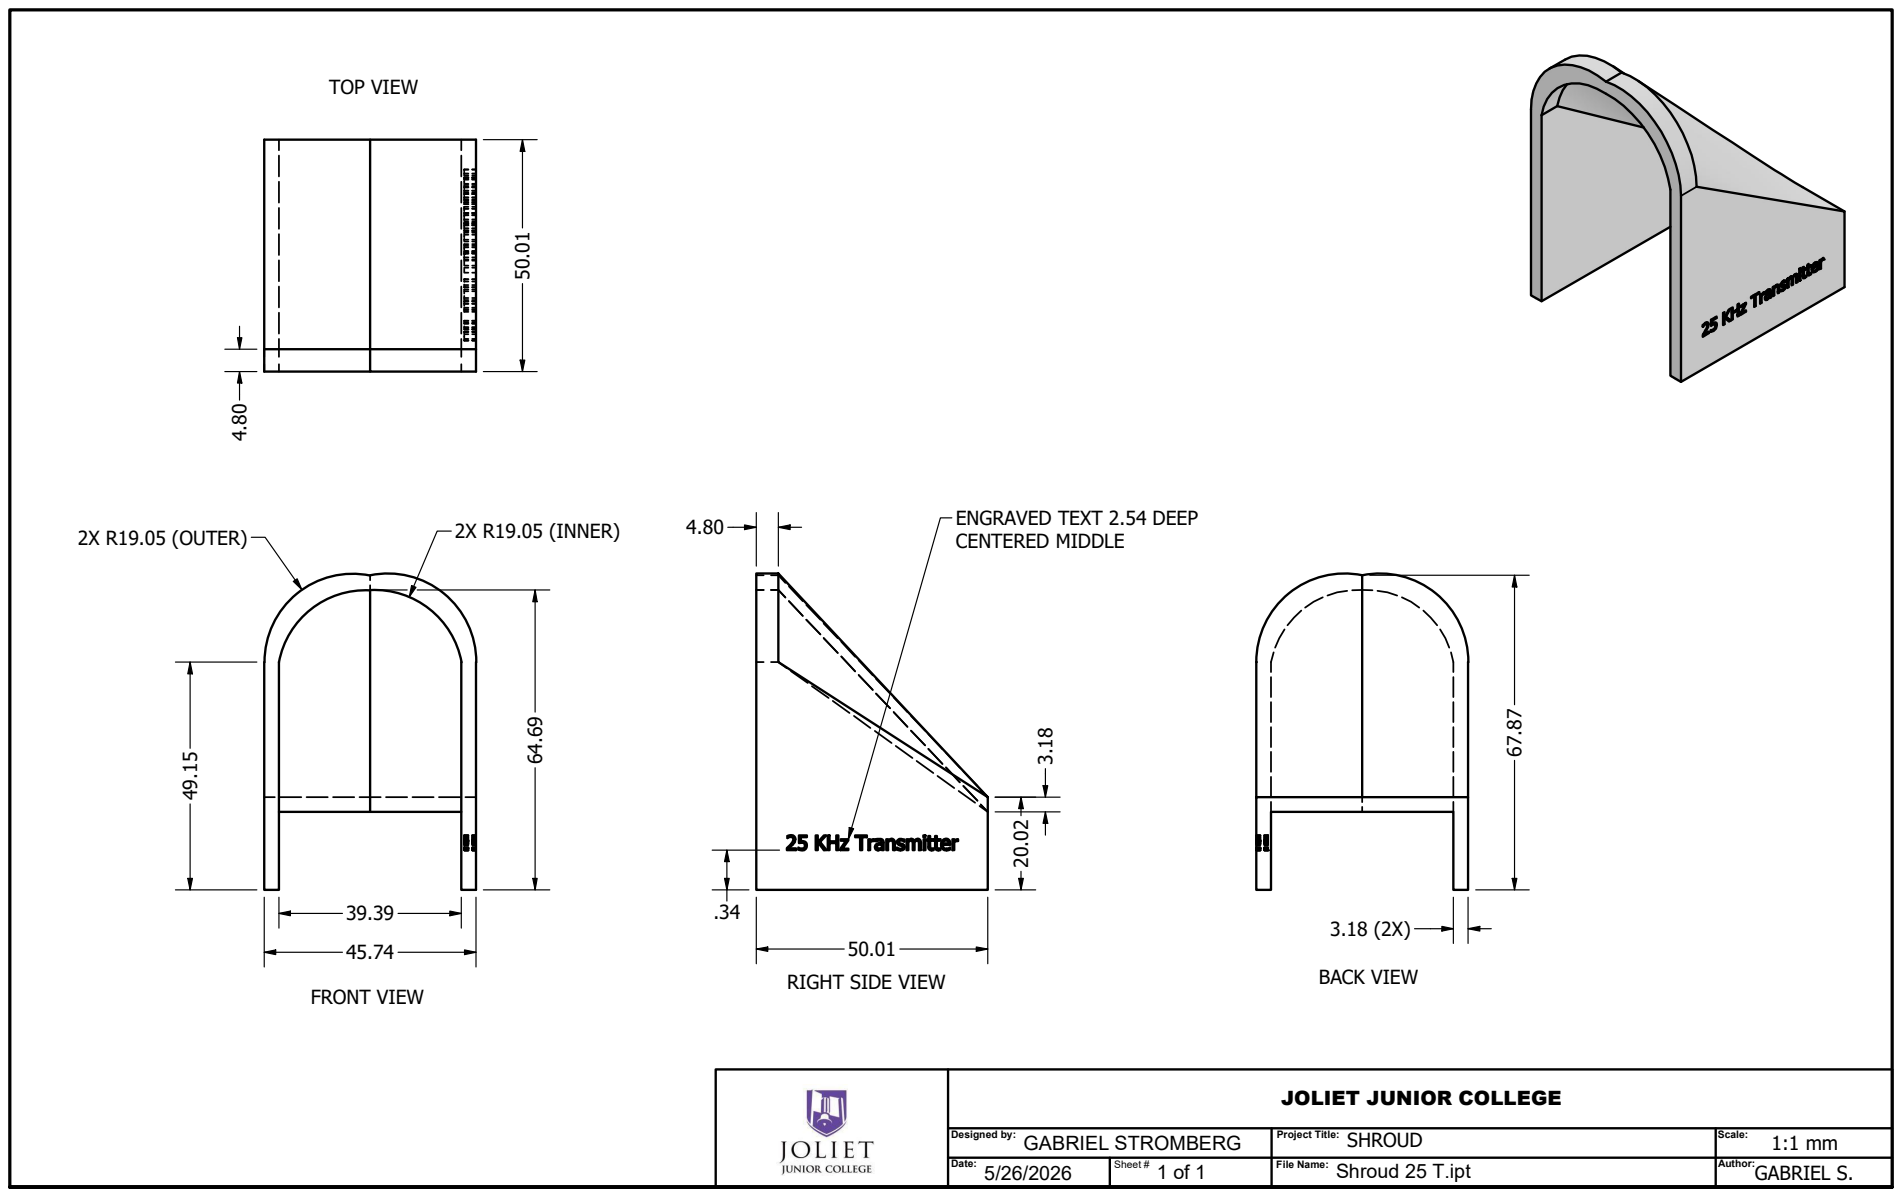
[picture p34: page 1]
2X R19.05 (INNER) 2X R19.05 (OUTER); TOP VIEW; FRONT VIEW; RIGHT SIDE VIEW; BACK VIEW

ENGRAVED TEXT 2.54 DEEP
CENTERED MIDDLE

JOLIET JUNIOR COLLEGE

Designed by: GABRIEL STROMBERG | Project Title: SHROUD | Scale: 1:1 mm

Date: 5/26/2026 | Sheet # | File Name: Shroud 25 T.ipt | Author: GABRIEL S.

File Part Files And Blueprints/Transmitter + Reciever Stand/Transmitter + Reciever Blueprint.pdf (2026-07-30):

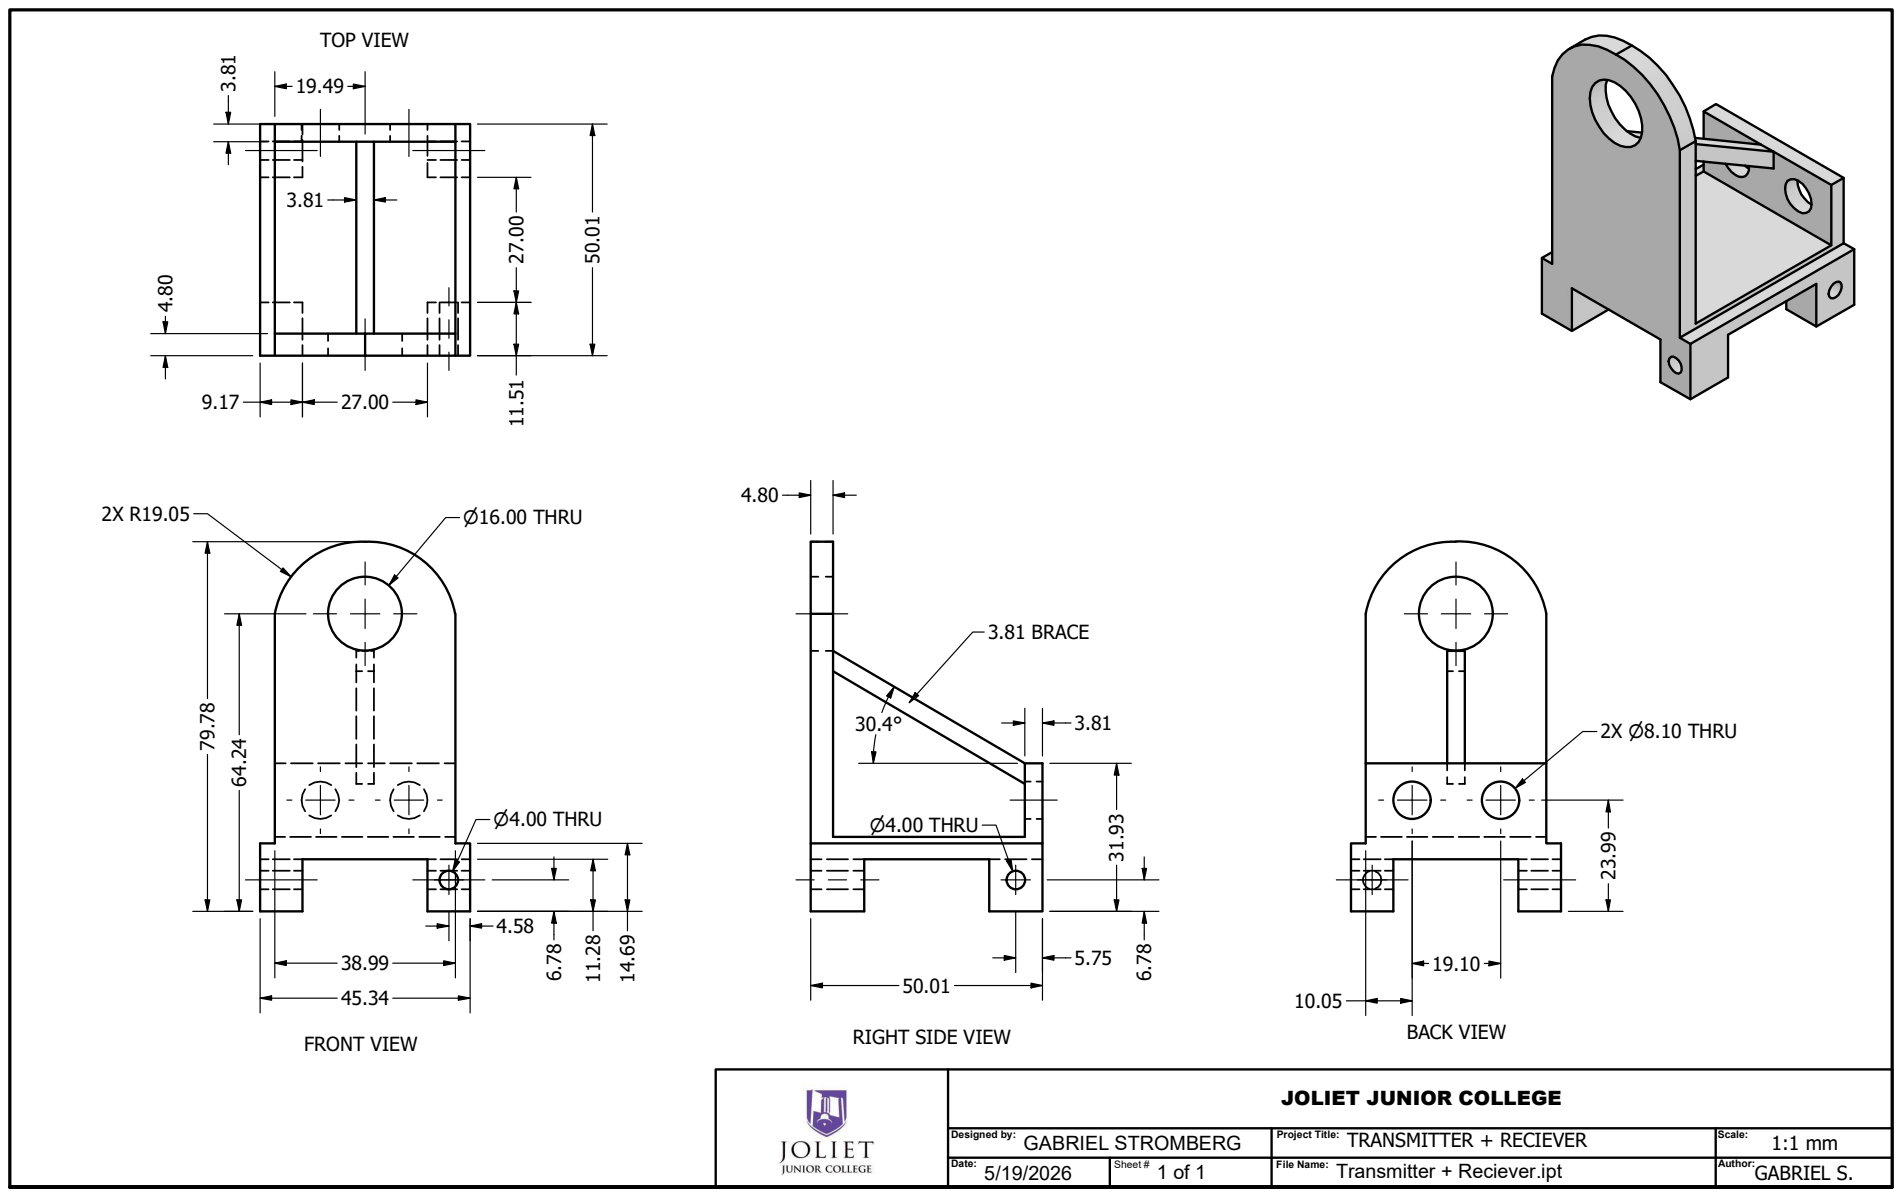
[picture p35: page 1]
⌀4.00 THRU; ⌀16.00 THRU; 3.81 BRACE; 2X ⌀8.10 THRU; TOP VIEW; FRONT VIEW; RIGHT SIDE VIEW; BACK VIEW

JOLIET JUNIOR COLLEGE

Designed by: GABRIEL STROMBERG | Project Title: TRANSMITTER + RECIEVER | Scale: 1:1 mm

Date: 5/19/2026 | Sheet # | File Name: Transmitter + Reciever.ipt | Author: GABRIEL S.

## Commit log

2026-07-30 Adding all files for initial commit
    [25 Khz double slit.dwg, 25 Khz double slit.dxf, 25 Khz single 1.dwg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]
2026-08-04 Add README and lab activity handouts
    Document the project: printed and laser-cut parts, print settings,
    probe assembly, and the lab activities built around these transducers.
    Also commit the Lab activities folder so the handouts the README
    references are present in the repo.
